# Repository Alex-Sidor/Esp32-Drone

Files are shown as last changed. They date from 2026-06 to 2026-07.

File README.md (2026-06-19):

This drone is primarily being made as a integration with my motion tracking system

my drone is comprised of
* 4x 8520 brushless dc motors
* 4x props (came with dc motors)
* 1x custom pcb (file linked)
* 1x Esp32 Devkit C3 (you can use whatever esp you want)
* 1x mpu6050
* 1x 3.8V 95C battery
* assorted capacitors (read on where to put them)
* rubber spacers to remove vibration from the mpu6050 (get better readings)
* long m2 bolts and nuts to secure top part

for the drone frame i used

`https://www.thingiverse.com/thing:1221911`

Here is a picture of the designed pcb

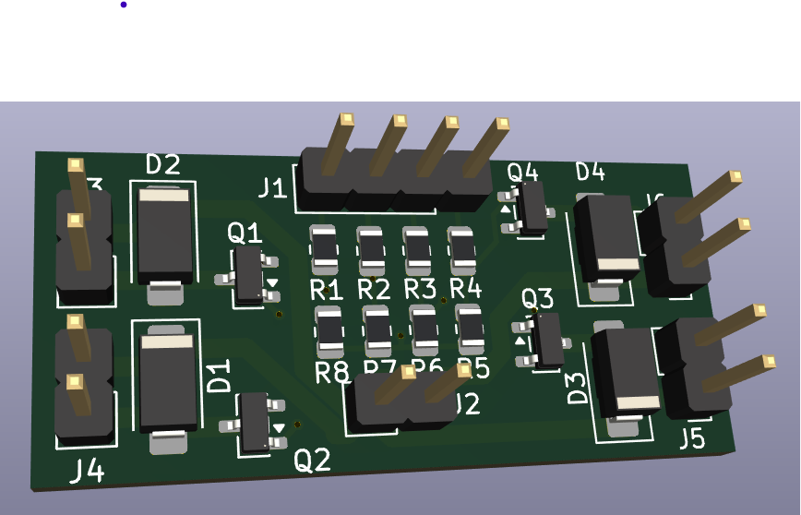
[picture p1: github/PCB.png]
PCB


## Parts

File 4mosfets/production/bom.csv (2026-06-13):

Designator | Footprint | Quantity | Value | LCSC Part #
D1, D2, D3, D4 | D_SMA | 4 | SS14
J1 | PinHeader_1x04_P2.54mm_Vertical | 1 | Conn_01x04_Pin
J2, J3, J4, J5, J6 | PinHeader_1x02_P2.54mm_Vertical | 5 | Conn_01x02_Pin
Q1, Q2, Q3, Q4 | SOT-23 | 4 | AO3400A
R1, R2, R3, R4 | 0805 | 4 | 220
R5, R6, R7, R8 | 0805 | 4 | 10k

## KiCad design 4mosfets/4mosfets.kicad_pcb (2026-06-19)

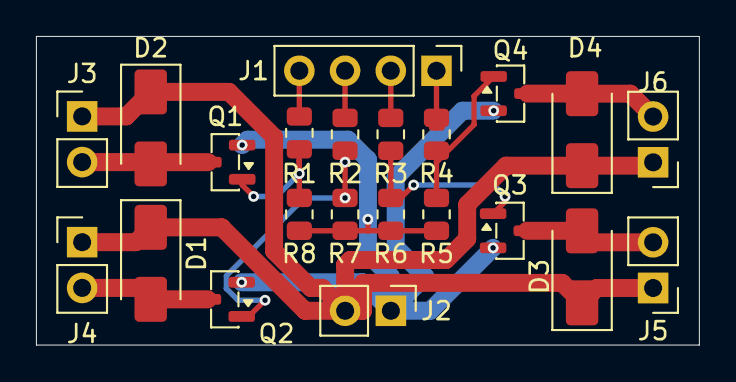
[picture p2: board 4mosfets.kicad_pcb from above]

Board: 2 copper layers, 36.8 x 17.1 mm, 22 parts (0 on the bottom side), 14 nets.

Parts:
D1, D2, D3, D4: SS14; D_SMA
J1: Conn_01x04_Pin; PinHeader_1x04_P2.54mm_Vertical
J2, J3, J4, J5, J6: Conn_01x02_Pin; PinHeader_1x02_P2.54mm_Vertical
Q1, Q2, Q3, Q4: AO3400A; SOT-23
R1, R2, R3, R4: 220; R_0805_2012Metric
R5, R6, R7, R8: 10k; R_0805_2012Metric

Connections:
/<NO NET>: J2.1, Q1.2 (S), Q2.2 (S), Q3.2 (S), Q4.2 (S), R5.2, R6.2, R7.2, R8.2
unnamed: D1.2 (A), J4.2, Q2.3 (D)
unnamed: D1.1 (K), D2.1 (K), D3.1 (K), D4.1 (K), J2.2, J3.1, J4.1, J5.1, J6.1
unnamed: D2.2 (A), J3.2, Q1.3 (D)
unnamed: D3.2 (A), J5.2, Q3.3 (D)
unnamed: D4.2 (A), J6.2, Q4.3 (D)
unnamed: J1.1, R4.1
unnamed: J1.2, R3.1
unnamed: J1.3, R2.1
unnamed: J1.4, R1.1
unnamed: Q1.1 (G), R1.2, R8.1
unnamed: Q2.1 (G), R2.2, R7.1
unnamed: Q3.1 (G), R3.2, R6.1
unnamed: Q4.1 (G), R4.2, R5.1

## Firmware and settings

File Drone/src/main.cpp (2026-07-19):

#include "freertos/FreeRTOS.h"
#include "freertos/task.h"
#include "driver/gpio.h"
#include "Motors.h"

#include "PID.h"

#include "Vector.h"
#include "MPU6050.h"

extern "C" void app_main(void)
{
    const gpio_num_t pins[4] = {
        GPIO_NUM_4,
        GPIO_NUM_5,
        GPIO_NUM_18,
        GPIO_NUM_19
    };

    DroneMotors m(pins);

    vTaskDelay(pdMS_TO_TICKS(2000));

    m.testMotors();

    vTaskDelay(pdMS_TO_TICKS(2000));


    MPU6050 imu;

    PID x(0.000,0,0.001);
    PID y(0.000,0,0.001);

    while(1){
        imu.update();

        Vec3 a = imu.getAngle();
        Vec3 r = imu.getRotVel();

        float dt = imu.getDT();

        Vec2 out;

        out.x = x.update(a.x,r.x,dt);
        out.y = y.update(a.y,r.y,dt);

        m.runMotors(out,0.0);

        ESP_LOGI("Main", "\nx=%.2f\ty=%.2f", out.x, out.y);

        vTaskDelay(pdMS_TO_TICKS(10));
        /*for(size_t i = 0; i < 10; i++){
            m.runMotors(Vec2(),((float)i)/10.0f);
            vTaskDelay(pdMS_TO_TICKS(100));
        }*/
    }
}

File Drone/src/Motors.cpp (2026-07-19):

#include "Motors.h"

DroneMotors::DroneMotors(const gpio_num_t motorPins[4]){
    for(size_t i = 0; i < 4; i++){
        motors[i] = motorPins[i];
    }

    ledc_timer_config_t ledc_timer = {
        .speed_mode       = LEDC_MODE,
        .duty_resolution  = LEDC_DUTY_RES,
        .timer_num        = LEDC_TIMER,
        .freq_hz          = LEDC_FREQUENCY,
        .clk_cfg          = LEDC_AUTO_CLK
    };
    ESP_ERROR_CHECK(ledc_timer_config(&ledc_timer));

    for (int i = 0; i < 4; i++) {
        ledc_channel_config_t ledc_channel = {
            .gpio_num       = motors[i],
            .speed_mode     = LEDC_MODE,
            .channel        = channels[i],
            .timer_sel      = LEDC_TIMER,
            .duty           = 0,
            .hpoint         = 0
        };
        ESP_ERROR_CHECK(ledc_channel_config(&ledc_channel));
    }
}

void DroneMotors::testMotors(){
    for(size_t i = 0; i < 4; i++){
        runMotor(i, 0.1);
        vTaskDelay(pdMS_TO_TICKS(100));
        runMotor(i, 0);
        vTaskDelay(pdMS_TO_TICKS(400));
    }
}

void DroneMotors::runMotor(int i, float thrust){

    thrust = minmax(thrust, 0, 1);
    thrust *= LEDC_MAX_NUMBER;

    ESP_ERROR_CHECK(ledc_set_duty(LEDC_MODE, channels[i], static_cast<uint32_t>(thrust)));
    ESP_ERROR_CHECK(ledc_update_duty(LEDC_MODE, channels[i]));
}

void DroneMotors::runMotors(Vec2 d, float thrust){
    
/*
o 2   +x   o 3

      /\
+y    ||   -y

o 1  -x   o 0
*/

    thrust = minmax(thrust, 0, 1);
    
    runMotor(0,minmax(-d.x - d.y + thrust, 0, 1));
    runMotor(1,minmax(-d.x + d.y + thrust, 0, 1));
    runMotor(2,minmax(d.x + d.y + thrust, 0, 1));
    runMotor(3,minmax(d.x - d.y + thrust, 0, 1));
}

float DroneMotors::min(float a, float b){
    if(a<b)
        return a;
    return b;
}

float DroneMotors::max(float a, float b){
    if(a>b)
        return a;
    return b;
}

float DroneMotors::minmax(float input, float bottom, float top){
    return(max(min(input,top),bottom));
}

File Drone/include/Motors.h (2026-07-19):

#pragma once

#include "freertos/FreeRTOS.h"
#include "freertos/task.h"
#include "driver/gpio.h"

#include "Vector.h"

#include <stdio.h>
#include "driver/ledc.h"
#include "esp_err.h"

#define LEDC_TIMER             LEDC_TIMER_0
#define LEDC_MODE              LEDC_LOW_SPEED_MODE
#define LEDC_CHANNEL           LEDC_CHANNEL_0
#define LEDC_DUTY_RES          LEDC_TIMER_10_BIT
#define LEDC_MAX_NUMBER        1023
#define LEDC_FREQUENCY         (20000)

class DroneMotors{
public:

    const ledc_channel_t channels[4] = {
        LEDC_CHANNEL_0,
        LEDC_CHANNEL_1,
        LEDC_CHANNEL_2,
        LEDC_CHANNEL_3
    };


    DroneMotors(const gpio_num_t motorPins[4]);

    void testMotors();

    void runMotor(int i, float thrust);

    void runMotors(Vec2 d, float thrust);

    float min(float a, float b);
    float max(float a, float b);
    float minmax(float input, float bottom, float top);

private:

    gpio_num_t motors[4];
    
};

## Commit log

2026-06-13 added driver pcb
    [4mosfets.kicad_pcb, 4mosfets.kicad_sch, bom.csv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]
2026-06-19 updated pcb to have contacts closer to edge
    [4mosfets.kicad_pcb]
2026-07-16 updated pcb
    [4mosfets.kicad_sch, positions.csv, untitled.kicad_sch]
2026-07-16 created platformio project and made motor test
2026-07-16 copied over pid class
2026-07-16 created pid class
2026-07-16 added motor init
2026-07-16 added LEDC writing
2026-07-17 fixed c -> cpp conversion errors and added to MPU6050 class
    [MPU6050.cpp]
2026-07-17 fixed motor testing
2026-07-17 added imu test to main
2026-07-17 added accelerometer angle reading
2026-07-17 removed first time reading and added gyro and acceleration readings
2026-07-17 added complamentry filter
2026-07-17 tested accelerometer values in output
2026-07-18 wrote to currentAcceleration variable
2026-07-18 changed angleFromAccel to output in correct axis
    [MPU6050.cpp]
2026-07-19 added pid loop to main
2026-07-19 changed motor order
2026-07-19 fixed motor orders
2026-07-19 added extra timer from start
2026-07-19 put gyro data into currentRotationalVelocity
